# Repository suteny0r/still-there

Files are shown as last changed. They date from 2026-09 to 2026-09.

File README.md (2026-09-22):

# Still There?

*Sentry goin' up.* A face-tracking pan/tilt turret on the Seeed Studio XIAO ESP32S3 Sense.

Camera pan/tilt turret built around the Seeed Studio XIAO ESP32S3 Sense (OV2640, 8 MB PSRAM).
Two MG90S metal-gear servos, on-device person detection (ESPDet-Pico, Espressif's YOLOv11-derived
tiny detector) or face detection (esp-dl) or motion detection, a proportional
tracking loop with scan-when-lost, a laser/LED "fire" output, and a web UI with live MJPEG.
Enclosure is parametric OpenSCAD (2021.01), five printed parts, no supports.

```
firmware/    PlatformIO project (Arduino core 2.0.17, espressif32 6.13.0)
hardware/    turret.scad, render scripts, stl/ output
```

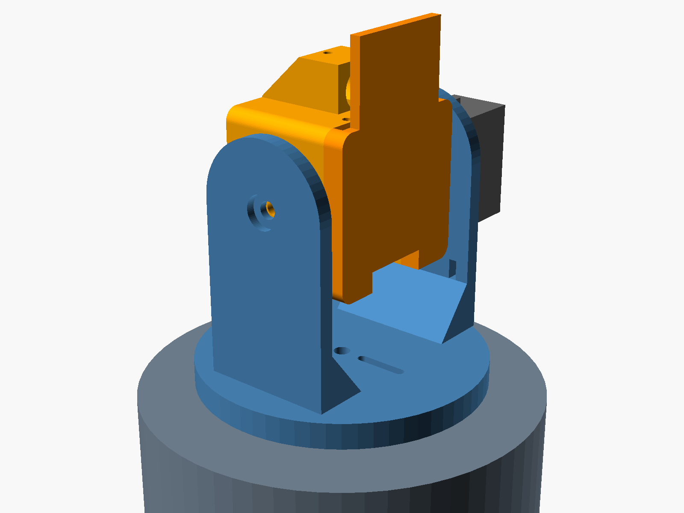
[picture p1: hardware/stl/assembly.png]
assembly


## Bill of materials

Purchase links for everything below except the board and servos: [BOM.md](BOM.md).

| Qty | Item | Notes |
|----:|---|---|
| 1 | Seeed Studio XIAO ESP32S3 Sense | with the camera expansion board fitted |
| 2 | MG90S 9 g metal-gear servo (SupSeek 4-pack or TowerPro) | 2.0 kg-cm @ 6 V, 20T spline, ships with single/double/cross horns |
| 1 | 6 mm laser diode module (optional) | 5 V, fits the saddle on the head |
| 1 | 470 uF+ electrolytic across servo 5 V/GND | servo current spikes reset the board otherwise |
| 1 | 5 V 2 A supply | USB-C into the base inlet or a panel-mount breakout |
| 6 | M2 x 8 self-tapping screws | 4 base lid, 2 head lid |
| 2 | M2 x 8 self-tapping screws | head wall into the single-arm horn (from inside the head) |
| 2 | M2 x 6 self-tapping screws | disc into the double-arm horn (from the top of the disc) |
| 4 | servo ear screws | supplied with the servos: 2 pan servo to base plate, 2 tilt servo to arm A |
| 2 | servo center horn screws | supplied with the servos |
| 1 | M3 x 12 screw | tilt pivot (arm B into the head) |
| 4 | 10 mm rubber feet | recesses in the base lid |

## Wiring

XIAO pin labels on the left, GPIO in brackets. Camera pins (GPIO 10-18, 38-40, 47, 48) and the
LED/SD-CS (GPIO 21) are used by the Sense board; D0-D3 are free.

| XIAO | GPIO | Function |
|---|-----:|---|
| D0 | 1 | pan servo signal |
| D1 | 2 | tilt servo signal |
| D2 | 3 | laser / LED (through a 100 R resistor or a transistor if > 20 mA) |
| D3 | 4 | trigger button to GND (optional, toggles laser) |
| 5V | | servo + laser power (USB 5 V passthrough) |
| GND | | common ground |

Power the servos from the 5 V pin only for bench tests with a supply into USB-C that can source
2 A. For anything more, feed 5 V into the base and run the riser harness up to the head (see
Wiring under Enclosure). The XIAO's own USB-C then stays free for flashing.

## Firmware

Face tracking depends on the esp-dl models that ship with arduino-esp32 **2.0.x**
(`libhuman_face_detect.a`, `libdl.a`). PlatformIO `espressif32 @ 6.13.0` pins that core. The Arduino
IDE with esp32 core 3.x compiles the same sources, but `HAVE_ESP_DL` resolves to 0 there and the Face
mode is disabled in the UI (motion, scan and manual still work).

### Build and flash (PlatformIO)

```
cd firmware
copy include\secrets.h.example include\secrets.h     # edit SSID / password
pio run -t upload
pio device monitor
```

Without `secrets.h` (or with an empty SSID) the turret starts an access point `turret` / `turret123`
at `http://192.168.4.1/`. On a LAN it is reachable at `http://turret.local/`.

Verified builds: PlatformIO env `xiao_esp32s3_sense` (1.53 MB flash, face detection linked), and
`arduino-cli compile --fqbn esp32:esp32:XIAO_ESP32S3:PSRAM=opi` on core 3.3.7 via
`firmware/make_arduino_sketch.ps1` (motion/manual only).

### Runtime

| Task | Core | Job |
|---|-----:|-----|
| `detect` | 1 | grab 240x240 RGB565, person (face acquire + torso color track) or motion (30x30 cell luma diff), feed tracker, draw overlay, JPEG, publish |
| `control` | 1 | 50 Hz: slew servos toward setpoints (rate + smoothing limits), scan sweep, laser |
| httpd :80 | 0 | `/` UI, `/status` JSON, `/control?var=&val=`, `/aim?x=&y=`, `/capture` |
| httpd :81 | 0 | `/stream` MJPEG of the latest published frame |

Tracking law: per detection, `setpoint += kp * (error / half-frame)` outside a pixel deadband;
the control task then moves at most `maxStep` degrees per tick. Motion detection is suppressed for
`settle` ms after any servo motion so the turret does not chase its own panning. After `lost` ms
without a target the pan sweeps between limits (`scan when lost`). When the aim point has stayed
inside the deadband for `lock ms`, the state is LOCK; with Auto-fire on, the laser follows LOCK.
LOCK has hysteresis: correction keeps running while locked, and the lock only releases when the error
exceeds `deadband x lock release` (default 3x) or the target is lost, so a slowly moving target is
followed with the laser held on.

Person mode: the esp-dl face detector (MSR01 + MNP01) only *acquires* the target. As soon as a face
is found, a CAMShift-style color tracker is seeded from the torso region below it (hue/saturation
ratio histogram against the whole frame) and follows the torso frame to frame at camera rate. The
face detector then re-runs every `face re-detect ms` (default 1 s) to re-anchor the track and refresh
the color model; between re-detections the person can turn, look away or walk sideways and the track
holds, because the torso tracker needs neither a frontal face nor a static background. When the color
match drops below `torso min confidence` for `lost` ms the track is dropped and the next face starts a
new one. "Torso color tracking" can be switched off to fall back to face-only tracking.

Aim point: the tracker centers a point `aim below` face-widths under the face center (default 2.3,
the chest; 0 = the face itself). While the torso tracker carries the target the same point is held at
a fixed proportion of the torso window, so it rides along with the person. Face width in pixels scales with 1/distance exactly like any body
offset does, so this is distance-independent: about 2.3 face-widths lands a laser boresighted
parallel to the camera on the chest at any range. The overlay draws the aim point tethered to the
face. The laser saddle sits ~20 mm above the lens, a fixed parallax that is negligible beyond a metre.

All tuning values are live in the web UI and persist to NVS with "Save settings".

Web UI keys: arrows nudge, Space centers, L toggles the laser, 1-4 select mode; click the image to
aim at that point.

Status LED (GPIO 21): fast blink while connecting, slow blink in AP mode, short blink while a
target is fresh, solid on LOCK.

### Servo pulse range

`SERVO_MIN_US`/`SERVO_MAX_US` are 544/2400 us (Arduino Servo defaults), which gives roughly 180 deg on
MG90S units. The TowerPro sheet quotes 1 to 2 ms for +-90; many clones need the wider range for
full travel. Check that neither servo buzzes at 0 or 180 before widening.

### Direction and trims

Scan when lost sweeps pan at "Scan tilt" in every tracking mode (fixed 2026-09-22: it used to hold
whatever tilt the last chase ended on, so it swept the floor or the ceiling). "Tracking tilt max"
(default 110) caps how far a tracking correction may tilt up, so a chase cannot end on the ceiling
lights; manual control keeps the full 35 to 145 range.

Servo orientation decides sign. If the head moves the wrong way, in manual control or by running
away from a target, toggle "Invert pan" or "Invert tilt" and press Save. The flag mirrors the servo
output about 90 degrees, so manual, scan, click-to-aim and tracking all reverse together. Pan/tilt
trim offsets the mechanical center. Both persist.

## Enclosure

`hardware/turret.scad` is a single parametric file. Select a part with `-D part="..."`.

| Part | Print orientation | Notes |
|---|---|---|
| `base` | top plate on the bed | pan servo goes in from below, body up through the plate cut, flange clamped against the two bosses with M2 screws driven up into the pilots; 6 x 12 mm arc slot for the harness outside the disc (a servo plug passes end-on), flat facet on the outside of the +X (back) wall for the USB-C inlet board (mounted outside, face flush, two M2 pilots 16 mm apart drilled from the facet), 13 mm connector slot open to the bottom rim (the lid closes it), vent slots |
| `base_lid` | flat | 4x M2 into wall bosses, rubber-foot recesses, vent grid |
| `yoke` | disc on the bed | double-arm horn channel underneath with two M2 slots and a 3.2 mm center hole; arm A carries the tilt servo (body outside, flange on the outer face) and a zip-tie slot near each edge for the harness; arm B has the M3 pivot with a countersink; arm B sits 2 mm further out than the head frame implies because the tilt horn seats 2 mm high on the spline (`sv_seat_extra_s`) |
| `head` | front face on the bed | camera module socket behind a 7.4 mm window, two standoffs bearing on the flex socket at the camera board's far end, which sits over its board-to-board connector (the end nearest the USB-C hangs free and gets no stop; the XIAO's exposed USB-end corners are the reset/boot buttons), a pad to the USB-C shell, lid posts behind the XIAO; 3 mm deep coax groove in the pivot-side wall; single-arm horn channel on +Y, M3 pivot boss on -Y; USB-C slot in the floor doubles as the harness entry; laser saddle on top (7.3 mm bore for the Quarton module, `laser_d`) with a lead-drop slot behind it; vent slots |
| `head_lid` | antenna plate on the bed | 3 mm friction lip, 2x M2 from the top wall, USB notch, outer face doubled to 4 mm over the whole lid and extended 15 mm above the head as a 2 mm fin for the 20 x 40 WiFi patch antenna (one flat face, prints on the bed), coax notch at the top corner on the pivot side continuing the head's wall groove out through the top edge |

Render everything:

```
cd hardware
powershell -ExecutionPolicy Bypass -File render.ps1      # or: bash render.sh
```

Output goes to `hardware/stl/` (five STLs plus `assembly.png`, `plate.png`). Then run
`python make_project.py --slice` to rebuild the Flash Studio project from the new STLs.
`-D part="assembly"` shows the whole turret with mock servos and board; `-D part="plate"` lays the
five parts out flat.

### Flash Studio project (Creator 5 Pro)

`hardware/turret_creator5pro.3mf` is a ready Flash Studio (Orca-Flashforge 2.4.2) project: all five
parts placed flat on the 256 x 256 plate, printer preset `Flashforge Creator 5 Pro 0.4 nozzle`,
unmodified stock process `0.20mm Standard @FF C5` (0.2 mm, 3 walls, 15 % grid infill, auto brim,
no support), filament `Flashforge PETG Basic @FF C5P`, bed type High Temp Plate (85 C). Open it with File > Open Project, or drag it onto the plate. Swap the filament preset to a
PLA one if you print PLA; the layout and process carry over. `turret_creator5pro_plate.png` shows the
first-layer footprint of each part on the bed. Sliced with these presets: about 3 h 10 min, 73 g of
PETG, no supports, no slicer warnings. Regenerate after CAD changes with `python make_project.py --slice`.
For a partial reprint add `--parts=head,head_lid` (any of base, base_lid, yoke, head, head_lid); the
project is written as `turret_creator5pro_<parts>.3mf`. In Flash Studio you can instead right-click the
unwanted objects and untick **Printable**, or select them and press Delete.

It was produced with the slicer's CLI (`flash studio.exe --load-settings ... --export-3mf`) after
flattening the preset inheritance chains; the CLI refuses system profiles that still carry
`inherits` and no `type` field.

Material: PETG is the better choice for this design. The 3 mm yoke arms, the 2.3 mm wall behind
the horn pocket and the M2 self-tapping pilots all load thin plastic; PETG's layer adhesion and
lower brittleness beat PLA there, and it does not creep under the constant preload of the friction
lip and screws inside a warm enclosure. PLA prints with tighter tolerances and better bridges, so
if you print PLA expect the friction lip to be snugger and drop `lip_clr` to 0.2 only if it turns
out loose. Either way the stock 0.20 mm Flashforge profile is the right starting point: its 3
perimeters fill every thin section of these parts solid, so infill settings barely matter, and no
supports are needed. Clearances (`clr`, `lip_clr`, `m2_*`/`m3_*` pilots) are at the top of `turret.scad`.

### Wiring

Everything electronic except the servos lives in the head, so one harness climbs from the base.
Pins below are the `xiao_espdet` build (the one in the turret): pan D0, tilt D1, laser D2, button D3.
The `*_expansion` builds move tilt to D2 and the laser to D6; do not wire the head from those.
22 AWG silicone wire. The two splice points are small perfboard scraps (about 4 x 6 holes) each
carrying a 3-pin male header so the servo plugs stay intact: the header sits in one row, every wire
gets its own hole in the header pin's row, and the row is bridged with solder. Never two wires on
one header tail.
MG90S lead colors: brown GND, red 5 V, orange signal. Power from one source at a time: either the
base inlet or the XIAO's USB-C, not both.

| Wire | From | To | Cut length |
|---|---|----|---|
| 5 V | inlet V pad | header A (base) -> header B (arm A) -> XIAO 5V pad | 60 + 180 + 80 |
| GND | inlet GND pad | header A -> header B -> XIAO GND pad | 60 + 180 + 80 |
| pan signal | header A (base) | XIAO D0 pad | 260 |
| tilt signal | header B (arm A) | XIAO D1 pad | 80 |
| laser + | XIAO 5V pad | laser red | 40 |
| laser - | laser black | 2N2222 collector; emitter to XIAO GND; base via 1 k to D2 | 40 |

1. **Base.** Screw the inlet board to the flat facet on the OUTSIDE of the back (+X) wall with two M2x4
   self-tapping screws, connector body through the 13 mm slot, solder pads facing the wall (they are
   reached through the slot from inside). The board face must sit at the wall surface or a plug
   cannot reach the receptacle; an inside mount was tried and failed for that reason. Board A: header in one row; row 1 takes the inlet V
   wire and the riser 5 V wire, row 2 the inlet GND wire and the riser GND wire, row 3 the riser
   pan-signal wire; bridge each row. Foam-tape board A to the inside of the lid or tie it to a lid
   boss. Plug the pan servo onto its header: orange on the signal pin. Twist the
   three riser wires, pass them up through the arc slot in the top plate, and leave a 40 mm loop
   above the plate for the pan swing. Screw the lid on.
2. **Yoke.** Zip-tie the riser against arm A's edge through the slot 10 mm above the disc. Board B
   rides under the same tie: row 1 takes the riser 5 V in and the head 5 V out, row 2 the same for
   GND, row 3 the tilt-signal wire from the head; bridge each row. Plug the tilt servo onto its
   header. The pan-signal wire passes board B untouched. (Alternative with no board on the yoke: cut
   the tilt servo plug off and heat-shrink splice its three leads to the riser wires, one joint each.)
3. **Head.** Four wires arrive from header B: 5 V, GND, pan signal, tilt signal. Give them a 20 mm
   loop under the head for the tilt swing and bring them in through the USB-C slot in the floor.
   Solder into the XIAO's plated THROUGH-HOLES from the back face: tinned wire in from the back,
   joint on the back, wire end trimmed flush at the front. Keep solder out of the edge castellations:
   the cavity leaves 0.5 mm per side and any bead on the edge jams the board. Holding the board
   back-face up with the USB-C at the top, the first holes down the RIGHT edge are D0 (pan), D1
   (tilt), D2 (laser), D3 (button), and the first two down the LEFT edge are 5V and GND; the
   silkscreen on the back confirms each one. Keep the joints low: the lid posts land at Y +-3.5
   beside the battery pads. Horn screws: use the two arm holes below the board's USB edge (more than
   11 mm from the hub); a screw head higher up sits against the board edge.
4. **Laser.** Push the module into the saddle, drop its leads through the slot behind the saddle.
   Red to the 5V pad. Black to the 2N2222 collector; emitter to the GND pad; base through 1 k to the
   D2 pad. Heat-shrink the transistor and tuck it behind the XIAO. Optional trigger button: D3 to GND.
5. **Check** before closing: 5 V supply on, both servos center on boot, laser toggles from the web UI,
   no wire crosses the tilt axis without slack. Flashing later: unplug the base inlet, use a
   right-angle USB-C cable in the floor slot beside the harness.

Build status (2026-09-21): prototype assembled and wired as above, person tracking follows a
moving target, laser fires from D2 through the 2N2222 driver. Tilt servo fitted with 2 mm of washers
pending the yoke reprint that moves arm B by the same amount.

### Assembly

1. Center both servos electrically first (flash the firmware, power up, wait for both to hit 90).
2. Base: fit the pan servo from below, body up through the plate cut, flange against the bottom of
   the two bosses, two M2 screws up into the pilots (the disc then rides about 1 mm off the plate).
   Screw the power inlet board to the outside facet (two M2x4), wire the base per Wiring, then screw on the lid.
3. Yoke: seat the **double-arm** horn in the channel under the disc (arms along the camera axis) and
   drive two M2 screws down through the slots into arm holes. Push the yoke onto the pan spline
   with the arms square to the camera direction and drive the horn screw down through the disc
   center hole; its head sits on the disc top. Do NOT fit the tilt servo yet: the head has no axial
   room to engage the spline once the servo is in the arm.
4. Head: lay the **single-arm** horn in the channel on the +Y face, arm pointing down (it may stick
   out ~3.5 mm past the bottom edge; trim it if you like) and drive two M2 screws from inside the head.
   Fit the board stack USB-C down: seat the camera module in the square socket first (lens through the
   window), let the flex socket at the camera board's far end settle onto the two standoffs and the
   USB-C shell onto its pad (nothing presses on the camera board's free end near the USB-C, nor on the
   XIAO's USB-end corners, those are the reset and boot buttons), then press the lid on (its posts stop 0.2 mm off the XIAO
   back) and drive the two M2 screws through the top wall.
5. Antenna (required: the XIAO ESP32S3 has no on-board antenna). The patch's adhesive is on the
   side opposite its coax, so the cable ends up on the exposed face. Stick the 20 x 40 patch to the
   outer face of the lid and fin, centered, top edge about 1 mm below the fin top. Inside the head
   the coax leaves the U.FL over the far edge or sideways at the corner into the 3 mm deep groove in
   the pivot-side wall, runs back along it, and goes straight up through the notch in the lid's top
   corner, out between the head's top wall and the fin. Outside it goes round the fin's side edge
   to the patch center (press one side of the U.FL plug in first, per Seeed). About 40 mm of the
   75 mm cable is used; loop the spare on the fin's inner face behind the laser saddle. `coax_side`
   in `turret.scad` mirrors groove and notch if your U.FL is on the other side.
6. Head onto the yoke: set the head between the arms with the pivot ring against arm B and drive the
   M3x8 through arm B into the ring. Then fit the tilt servo from OUTSIDE arm A, output end first,
   body through the cutout, spline into the horn hub, and drive its two flange screws into the arm.
7. Optional laser: push the module into the saddle bore (7.3 mm for the Quarton), M2 set screw from the top.

### Dimensions that matter

All at the top of `turret.scad`, mm:

- `sv_*`: MG90S envelope from the TowerPro configuration table (A 32.5 ear span, B 22.8 body,
  C 28.4 bottom to spline top, D 12.4 width, F 18.5 bottom to ear top). The body through-cuts use a
  looser 23.6 x 12.8 envelope because clones measure up to 23.9 x 12.7; the ear screws (slotted
  pilots, 27.3 to 28.3 mm spacing) locate the servo.
- Servo and horn dimensions measured on the SupSeek MG90S kit (two units), 2026-09-11:

  | | measured | in CAD |
  |---|---|---|
  | body length x width | 22.8 x 12.4 | 23.6 x 12.8 cut + clearance |
  | ear span (H) | 32.2 | ears rest on the surface, no cut |
  | ear hole spacing | 27.8 / 28.0 | slotted pilots 27.3 to 28.5 |
  | ear top to boss top (K) | 7.3 / 7.5 | 7.4 |
  | hub diameter | 6.8 | 7.4 counterbore |
  | arm plate thickness (E) | 2.0 | 2.6 recess |
  | arm width (D) | 5.1 | 6.1 channel |
  | single arm, center to tip (C) | 18.0 | head channel, open to the bottom edge |
  | double arm, tip to tip (J) | 31.2 | disc channel |
  | single arm: boss top to arm face / hub top | 3.8 / 6.4 | head gap; 5.8 deep hub counterbore (horn wall 6.5) |
  | double arm: boss top to arm face / hub top | 5.85 / 6.26 | disc height; 3.6 deep counterbore (disc 5.0) |

  The kit's cross horn is asymmetric (~31 mm long axis) and does not fit the head, so the pan disc
  takes the **double arm** and the head the **single arm**, pointing down (it extends ~3.5 mm past
  the head's bottom edge; trim it flush if you like). Pockets are rounded channels with one
  continuous M2 screw slot per arm, so hole positions in the horn do not matter. The horn screw on
  the disc sits on top without a countersink. `gap_margin` (0.8) still biases toward the hub seating
  slightly short rather than the head rubbing the arm.
- Board stack (XIAO ESP32S3 **Plus** 17.76 x 21.25 with the camera board, measured 2026-09-13):
  lens front to XIAO back 13.44, lens front to XIAO top face 12.30, 3.0 mm board-to-board gap,
  camera board 18 x 15 (wider than the XIAO, flush with its far end), 8 x 8 module housing with a
  7 mm barrel, lens center 10.8 above the USB edge and on the board centerline. The camera module
  hangs on a short flex and is **not** fixed to the camera board: the head holds it in an 8.6 mm
  square socket behind a 7.4 mm window, so the flex pushes it into the socket. The XIAO is located
  by two pads on its exposed USB-end corners and four lid posts (0.2 mm clearance, no squeeze); two
  standoffs on the flex socket at the camera board's far end and a pad on the USB-C shell are the front stops (0.2 mm clearance)
  without loading the connector. `lens_protrude` (2.3, barrel past the housing face) is derived, not
  measured; the flex absorbs a couple of mm either way.
- `axis_h` 34: tilt axis above the disc. Raise it if you use a straight USB-C plug in the head.
- Tilt limits in firmware (`TILT_MIN_DEG`/`TILT_MAX_DEG`, 35..145) keep the head off the yoke;
  pan is 0..180.

## Known limits

- esp-dl face detection at 240x240 takes 100-200 ms; in Person mode it only runs on acquisition and
  every `face re-detect ms`, so the torso tracker and the stream run at 10-20 fps in between. The
  stream and detection share one frame pipeline, so the stream stutters on re-detect frames.
- The torso tracker is a color tracker: a person whose shirt matches the background, or two people in
  the same shirt, will confuse it. The ratio histogram suppresses background colors but not another
  identical shirt. The face re-detect re-anchors it every second, which limits how far it can wander.
- Motion mode re-references every frame; a target that stops moving disappears until `lost` expires.
- The USB-C slot in the head floor assumes a right-angle cable that runs backward; a straight plug
  hits the yoke disc when tilting down.

## Whole-body person detection: env `xiao_espdet` (default build)

Two firmware flavours live side by side. `xiao_esp32s3_sense` / `xiao_expansion` are the original
esp-dl 1.x face acquisition + torso color tracking on arduino-esp32 2.0.17. `xiao_espdet` (developed
on the `espdet-pico` branch, now merged) swaps the acquisition detector for Espressif's ESPDet-Pico pedestrian model
(esp-dl 3.3.11, `espressif/pedestrian_detect` 0.3.2, 224x224 input). A body box does not need a
frontal face, so masked, turned-away or side-on people are acquired, and the aim point is a fraction
down the box (`aim down body`, default 0.25) instead of "below the face".

ESPDet is Espressif's family of tiny object-detection models (the main variant is ESPDet-Pico)
built for running on ESP32-class microcontrollers. It comes out of the esp-detection project, which
provides a series of ultra-lightweight models along with APIs for training custom detection models
tailored to specific use cases, optimized for efficient deployment on ESP AI chips, and is based on
Ultralytics YOLOv11.

Measured on the XIAO ESP32S3 Sense (2026-09-11): detector 190 to 210 ms per run including the
resize, scores 0.5 to 0.86 on a seated person with a mask, torso tracker 6 to 15 ms between runs,
overall 6 to 7 fps with re-detection every 300 ms, 110 KB heap / 6.7 MB PSRAM free, no resets.

How it is built (no ESP-IDF CMake, no component manager):

- Platform: pioarduino `stable` (Arduino 3.3.6 on the IDF 5.5 SDK), plain `framework = arduino`.
  This is the same platform your other pioarduino projects use. esp-dl 1.x face models do not exist
  on this core, so `HAVE_ESP_DL` is 0 and `HAVE_ESPDET` is 1.
- `firmware/lib/espdl`: esp-dl 3.3.11 subset for ESP32-S3 (dl core, xtensa + TIE-728 assembly
  kernels, fbs_loader, vision/detect, vision/image without JPEG/PPA/YUV/HSV) as a PlatformIO
  library; the prebuilt `libfbs_model.a` is linked by `link_fbs.py`. Kconfig options are supplied
  as `-D` flags in `platformio.ini`.
- `firmware/lib/pedestrian_detect`: the component's `.cpp/.hpp` plus the model, packed with esp-dl's
  `pack_espdl_models.py` and embedded 16-byte aligned through `model/pedestrian_detect_model.S`
  (`.incbin`), which provides the `_binary_pedestrian_detect_espdl_start` symbol the component expects.
- `person_detect.cpp` wraps `PedestrianDetect`; the torso color tracker, lock logic, web UI and
  servo control are unchanged. Person mode seeds the torso tracker from the upper 35 % of the body box.
- Camera task stack is left at the SDK default here; the frame-copy and log-sink fixes from `main`
  still apply.

Build / flash from **PowerShell or VS Code**, not Git Bash: pioarduino's tool installer refuses to
run under MSYS (`ERROR: MSys/Mingw is not supported`) and the compiler is then not found.

    pio run -e xiao_espdet -t upload --upload-port COM13

`xiao_espdet` is the enclosure build: bare XIAO in the head, pins pan D0, tilt D1, laser D2, button
D3 as in the pin table, no OLED or buzzer code. For bench work with the XIAO on the Seeed Expansion
Board use `xiao_espdet_expansion` (same detector; tilt D2, laser D6, button D1, buzzer D3, OLED on
D4/D5). The board in the turret was flashed with `xiao_espdet` on 2026-09-18.

Flash use is 3.0 MB of the 3.3 MB app slot. If it grows, switch `board_build.partitions` to
`max_app_8MB.csv` (drops OTA).

Falling back to the face build is a reflash: `pio run -e xiao_expansion -t upload --upload-port COM6`.
NVS settings are shared (same keys). The turret powers up in the mode that was active when settings
were last saved (default Person).

## Bring-up notes (2026-09-10, board on the XIAO Expansion Board, no servos)

- Build/flash: `pio run -e xiao_expansion -t upload --upload-port COM6`. The expansion env moves the
  tilt servo to D2 and the laser to D6 because the expansion board owns D1 (user button) and D3
  (buzzer); it adds the SSD1306 status page (OLED found at 0x3C) and buzzer cues.
- Camera image was upside down in this mounting: set H-mirror and V-flip in the UI and Save. The
  head-mounted orientation will differ; set it once there.
- Crash found and fixed: panic "Stack canary watchpoint triggered (cam_task)". The camera driver's
  2 KB task logs `EV-VSYNC-OVF` through vprintf whenever a frame is held too long; the newlib lock
  setup inside that printf overflows the stack. Fixes: the detector now copies each frame to PSRAM
  and returns the driver buffer immediately, the driver gets 3 buffers, and the IDF log vprintf is
  replaced with a no-op (`esp_log_level_set` was not sufficient in this SDK build). A bare
  `cam_hal: EV-VSYNC-OVF` line can still show on the console now and then; it comes through the ROM
  printf and is harmless.
- Second crash found and fixed: heap corruption (`StoreProhibited`/`LoadProhibited` in the WiFi task
  a few seconds after the first face detection). `fb_gfx` has no bounds checking at all. Two overlay
  writes left the frame: the face-center marker at `y-2` with the face at the top edge (where
  `aim below` puts it), and the "face NNNms" text placed 14 px above the bottom while the fb_gfx
  font (FreeMonoBold 12pt) draws 24 rows downward. Every overlay primitive, text included, now goes
  through clipped helpers, and the PSRAM work frame has 8 KB guard bands on both sides.
- After the person leaves, the torso color tracker can keep matching background at its minimum
  window size; a track with no detector confirmation for `faceTimeoutMs` is dropped (default 1.5 s
  since 2026-09-22, was 8 s: long enough for a color track on a blank wall to drive a servo to its stop).
- Acquisition gate (2026-09-22): a new track needs two detections within 0.9 s; a single hit on a
  lamp does not repeat, a person does. A box wholly in the top quarter of the frame while tilt is at
  its tracking ceiling is ignored. A torso window that stays put for a second while the servos are
  still slewing is tracking nothing and is dropped.
- LEDC: ESP32-S3 allows at most 14-bit PWM resolution; the servo driver asked for 16 and silently
  failed. Now 14-bit (1.2 us per step at 50 Hz).
- The esp-dl face model does not detect masked faces. Acquisition needs an unmasked, roughly
  frontal face; a mask blocks Person mode acquisition entirely (torso tracking still works once
  acquired).
- Pipeline rates on the S3: 10 fps in Manual (deliberately capped), 15-16 fps in Person mode while
  no face is present (stage-1 detector 6-14 ms), stream to a PC over the AP at the same rate.
- Opening the USB serial port from a host tool resets the board (USB-Serial-JTAG DTR/RTS). Test
  over HTTP and open serial only when you want a fresh boot log.

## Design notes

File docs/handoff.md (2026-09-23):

# Handoff — still-there evaluation (2026-09-22)

## Objective
- Evaluate the codebase at `F:\still-there` — a face-tracking pan/tilt turret firmware + hardware project (architecture, code quality, potential issues, build health) and produce a final evaluation report

## Important Details
- PlatformIO project targeting Seeed Studio XIAO ESP32S3 Sense (OV2640 camera, 8 MB PSRAM, qio_opi)
- espressif32 6.13.0 / Arduino core 2.0.17; **default env `xiao_esp32s3_sense`**
- Three build envs: `xiao_esp32s3_sense`, `xiao_expansion` (SSD1306 + buzzer), ESPDet-Pico (pioarduino / Arduino 3.3.x / IDF 5.5)
- `lib_ignore = espdl, pedestrian_detect` in base — vendored esp-dl 3.x libs excluded from default and expansion envs
- Build flags: `-DFACE_TWO_STAGE=1`, `-DCAMERA_MODEL_XIAO_ESP32S3`, `-DBOARD_HAS_PSRAM`
- Architecture: `detectorTask` (core 1, 240x240 RGB565 -> detect -> tracker -> overlay -> JPEG -> FrameStore), `controlTask` (core 1, 50 Hz servo slew/scan/laser), `httpd` (core 0, :80 UI+JSON, :81 MJPEG), `loop()` (status LED, trigger button)
- **IDF log sink no-op**: `idfLogSink()` replaces `esp_log_set_vprintf` to prevent 2 KB cam_task stack overflow from EV-VSYNC-OVF -> vprintf -> newlib lock creation; ROM printf path still emits the short line (harmless)
- Tracker control: proportional correction (kp=18 deg) outside deadband (12 px), hysteresis lock release via `lockRelease` factor (3.0x deadband), `lockMs=600`, `settleMs=350`, `lostMs=2500`, `maxStep=3 deg/tick`
- `aimPoint()`: FACE -> y + 2.3*w below; PERSON -> y - h/2 + 0.25*h; TORSO -> torsoAimY
- Color tracker: 74-bin (12 hue x 6 sat + dark + gray) normalized ratio histogram; 8-iteration mean-shift; 1.4x search window; 0.05 per-bin threshold; `minConfidence=0.12`
- Motion detection: 30x30 grid, 2 px subsample per cell, luma from RGB565, frame-to-frame differencing with threshold + weighted centroid + bounding box
- Face detection: two-stage MSR01->MNP01 or single-stage; Person detection: `PedestrianDetect` (PICO_S8_V1) with `HAVE_ESPDET`
- Servo: LEDC 50 Hz, LEDC_CH_PAN=2, LEDC_CH_TILT=3, 14-bit (S3 max), range 544-2400 us; PAN 0-180 deg, TILT 35-145 deg, center 90/90
- `trackTiltMax=110 deg` caps tracking tilt; `torsoTrack=true` default
- OLED: I2C bus recovery, probe every 2 s for 30 s, re-init every 15 s; U8g2_SSD1306_128X64
- Camera 240x240, XCLK 20 MHz; `CONTROL_HZ=50`
- Web: MJPEG port 81, JSON port 80, mDNS `turret`; AP fallback `turret`/`turret123`
- Hardware: parametric OpenSCAD enclosure, 2x MG90S metal-gear servos, 5 printed parts
- BOM: PETG Pro filament, M2 self-tapping screws, M3 button-head Torx (tilt pivot), 470 uF electrolytic cap, 5 V 3 A USB-C supply
- web.cpp full review (287 lines, complete):
  - Routes: `/` (INDEX_HTML), `/status` (JSON, no-store), `/control?var=&val=` (GET, all settings, constrained), `/aim?x=&y=` (click-to-aim), `/capture` (single JPEG, heap alloc 96 KB), `/stream` (MJPEG multipart, 96 KB heap alloc, poll for new seq up to 2 s, break on send error, free buf)
  - Two httpd instances (core 0), ctrl_port 32768/32769, ctrl stack 6144; stream cfg `max_open_sockets = 3`
  - CORS `Access-Control-Allow-Origin: *` on control/capture/stream
  - `defaults` handler preserves hmirror/vflip, resets rest
  - `faceOk` reported via HAVE_ESP_DL compile-time, `detector` name: espdet-person / esp-dl-face / none
  - X-Framerate header hard-coded 60 (aspirational, not real)
  - No auth on any endpoint; control is unbounded-GET (CSRF-able from any page pointed at device); no rate limiting at IP level (httpd default connection limits only)
  - `capture_handler` and `stream_handler` malloc 96 KB heap each — concurrent stream + capture = 192 KB heap pressure
- color_tracker.cpp full review (126 lines, complete):
  - mean-shift: 8 iterations, `STEP` subsample (2 px), per-bin threshold v<0.05 skip, m00 minimum 1.0, converge when moved < 1.0 px
  - Window adaptation: `area = m00*STEP*STEP`, aspect from seed, clamp to 0.5x-1.8x seed, EMA 0.7/0.3
  - `_conf = area/(sw*sh)` where sw/sh are the 1.4x windows; minConfidence 0.12
  - `t.kind = TARGET_TORSO` — color tracker is the torso/presence fallback, not face
  - Histogram is a ratio hist (roi/all) normalized by max, so illumination-common modes wash out
  - `binOf` computes hue with integer math from 565 bits; dark (mx<40) and gray (s<40) are separate bins

## Work State
### Completed
- Listed top-level directory structure, globbed all firmware source files
- Read `README.md`, `platformio.ini` (all 3 envs), `tracker.h` (Settings, Mode, API)
- Read `detector.h` (complete), `servo_ctl.h` (complete), `person_detect.cpp` (complete), `web.h` (complete), `display.h` (complete), `frame_store.h` (complete), `camera_pins.h` (complete)
- Read `detector.cpp`: `begin()`, `detectFace()`, `detectMotion()` body (grid luma differencing, centroid, bbox)
- Read `config.h`: WiFi, pins, servo config, mechanical limits, camera, CONTROL_HZ (75 lines, complete)
- Read `display.cpp`: I2C bus recovery, OLED probe, init, `displayBegin`, start of `displayUpdate` (lines 1-54 confirmed; buzzer section and rest of draw not seen)
- Read `main.cpp`: includes, fb_gfx fallback stubs, task architecture comments, `idfLogSink` reference (lines 1-37 confirmed; detectorTask/controlTask/loop not seen)
- Read `web.cpp` **COMPLETE** (287 lines): index/status/control/aim/capture/stream handlers, webBegin config
- Read `tracker.cpp`: `writeServos` (invert about 180 + trim), `begin` (laser pin, LEDC, prefs, center), `setMode`, `aimPoint` start (lines 1-44 confirmed; controlTask tick, scan sweep, `update()` not seen)
- Read `color_tracker.h` (full), `color_tracker.cpp` **COMPLETE** (126 lines): binOf, clampBox, buildHist, init, refresh, track
- Read `docs/session-2026-09-10.md`: original creation request and session transcript (partial)
- Read `BOM.md`: parts list with Amazon links (partial, first 5 rows)

### Active
- Key sections still unreviewed due to truncation: `main.cpp` (detectorTask body, controlTask body, loop()), `tracker.cpp` (controlTask tick, scan sweep logic, `update()`), `display.cpp` (buzzer code, rest of `displayUpdate` draw)
- `index_html.h` (10309 B) not yet read
- `hardware/turret.scad` not yet reviewed
- **Final evaluation report not yet produced**

### Blocked
- (none)

## Next Move
1. Read `main.cpp` detectorTask/controlTask/loop (use offset/limit reads)
2. Read `tracker.cpp` controlTask/scan/update (use offset/limit reads)
3. Read `display.cpp` buzzer section + rest of draw
4. Read `index_html.h` (embedded web UI)
5. Optionally review `hardware/turret.scad`
6. Produce final evaluation report: architecture assessment, code quality observations, potential issues/risks, build health, recommendations

## Relevant Files
- `F:\still-there\README.md`: project overview, features
- `F:\still-there\BOM.md`: parts list with purchase links — partially read
- `F:\still-there\firmware\platformio.ini`: build config, 3 envs, pin/camera flags, lib_ignore
- `F:\still-there\firmware\src\main.cpp` (~19918 B): entry point, idfLogSink, task architecture — detectorTask/controlTask/loop not yet seen
- `F:\still-there\firmware\include\config.h` (75 lines): complete
- `F:\still-there\firmware\src\tracker.h`: Settings struct, Mode enum, Tracker API
- `F:\still-there\firmware\src\tracker.cpp`: writeServos, begin, aimPoint, onDetection — controlTask/scan/update not yet seen
- `F:\still-there\firmware\src\detector.h` (60 lines): complete
- `F:\still-there\firmware\src\detector.cpp`: detectFace, detectMotion (grid luma)
- `F:\still-there\firmware\src\servo_ctl.h` (57 lines): LEDC servo control, complete
- `F:\still-there\firmware\src\person_detect.cpp` (52 lines): ESPDet-Pico person detector, complete
- `F:\still-there\firmware\src\color_tracker.h`: full class definition
- `F:\still-there\firmware\src\color_tracker.cpp` (126 lines): **COMPLETE**
- `F:\still-there\firmware\src\web.h`: HTTP server API, complete
- `F:\still-there\firmware\src\web.cpp` (287 lines): **COMPLETE**
- `F:\still-there\firmware\src\display.h/.cpp`: OLED/buzzer — buzzer / rest of draw not seen
- `F:\still-there\firmware\src\frame_store.h` (46 lines): mutex-protected JPEG buffer, complete
- `F:\still-there\firmware\include\camera_pins.h` (20 lines): OV2640 pins, complete
- `F:\still-there\firmware\src\index_html.h` (10309 B): embedded web UI — not yet read
- `F:\still-there\docs\session-2026-09-10.md`: session transcript — partially read
- `F:\still-there\hardware\turret.scad`: parametric OpenSCAD enclosure — not yet reviewed
- `F:\still-there\hardware\stl\`: exported STL parts
- `F:\still-there\firmware\lib\pedestrian_detect\README.md`: person detector lib notes

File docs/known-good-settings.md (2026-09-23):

# Known-Good Settings

Captured live from `http://192.168.4.1/status` on **2026-09-22** after a full reset-to-defaults plus the intentional changes below. Verified working: face detection, lock, and laser hold steady on a stationary target (no more ~1.5 s lock-loss cycle).

## Intentional changes vs. code defaults

| Setting | Live value | Code default | Purpose |
|---|---|---|---|
| deadbandPx | 41 | 12 | Wider no-correction radius, calmer holding |
| invertPan | true | false | Pan servo wiring direction |
| invertTilt | true | false | Tilt servo wiring direction |
| scanSpeed | 9.0 | 25.0 | Slower lost-target sweep |
| scanTilt | 88.0 | 90.0 | Scan altitude |
| trackTiltMax | 84.0 | 110.0 | Tracking never tilts above this |
| aimFrac | 0.65 | 0.25 | Aim lower down the body box |
| personThr | 0.85 | 0.5 | Stricter person-box score threshold |
| faceTimeout | 25000 ms | 1500 ms | Long grace before dropping color torso track |
| autoFire | true | false | Laser follows lock state |
| motionMinCells | 49 | 3 | Higher motion trigger bar |
| hmirror | true | false | Mirror image for web view |

All other settings are at code defaults (kp=18, smooth=0.35, maxStep=3, settle=350, lost=2500, scan=true, lockMs=600, lockRelease=3.0, aimBelow=2.30, torso=true, redetect=300, torsoConf=0.12, autoFire aside, mthr=22, quality=80, panTrim=0, tiltTrim=0, bootMode=1/Person, mode=Person, detector=espdet-person, vflip=false).

## Full live status snapshot (2026-09-22, untracked/scanning state)

```json
{"mode":1,"pan":53.6,"tilt":88.0,"panSet":53.3,"tiltSet":88.0,"found":false,"fresh":false,"tx":0,"ty":0,"tw":0,"th":0,"score":0.00,"locked":false,"scanning":true,"laser":false,"moving":true,"fps":4.0,"infer":194,"rssi":0,"heap":116376,"psram":6814724,"uptime":2145,"resetReason":1,"faceOk":false,"kp":18.0,"smooth":0.35,"maxStep":3.0,"dead":41,"invPan":true,"invTilt":true,"settle":350,"lost":2500,"scan":true,"scanSpeed":9.0,"scanTilt":88.0,"trackTiltMax":84.0,"lockMs":600,"lockRelease":3.0,"aimBelow":2.30,"torso":true,"redetect":300,"torsoConf":0.12,"kind":0,"faceAge":-1,"faceTimeout":25000,"aimFrac":0.65,"personThr":0.85,"detector":"espdet-person","autoFire":true,"mthr":22,"mmin":49,"quality":80,"hmirror":true,"vflip":false,"panTrim":0.0,"tiltTrim":0.0,"bootMode":1}
```

## Reapplying from scratch (via web API)

Device is AP-mode: SSID `turret`, pass `turret123`, IP `192.168.4.1` (defaults; fine in source).
Endpoint: `GET /control?var=<name>&val=<value>&save=1` (param names per `web.cpp:120-172`).

```
/control?var=invpan&val=1&save=1
/control?var=invtilt&val=1&save=1
/control?var=dead&val=41&save=1
/control?var=scanspeed&val=9.0&save=1
/control?var=scantilt&val=88.0&save=1
/control?var=ttmax&val=84.0&save=1
/control?var=aimfrac&val=0.65&save=1
/control?var=personthr&val=0.85&save=1
/control?var=facetmo&val=25000&save=1
/control?var=autofire&val=1&save=1
/control?var=mmin&val=49&save=1
/control?var=hmirror&val=1&save=1
```

Notes:
- Keep `redetect` (300) well below `faceTimeout` (25000). The original lock-loss bug was `redetect=3700` > old `faceTimeout=1500`, which force-dropped the torso track every 1.5 s (`main.cpp:288`, `tracker.cpp:91`).
- `faceTimeout` is exposed in status as `faceTimeout` but set via var name `facetmo` (`web.cpp:149`).
- The Windows Wi-Fi profile for `turret` was set to auto-connect (connection mode was "manual"), so the AP link now survives device reboots without a manual `netsh wlan connect`.

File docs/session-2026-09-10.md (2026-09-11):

# Turret project session transcript

Source: `session-2026-09-10.jsonl`  
Rendered: 2026-09-10 19:31

## User  `15:23:03`

create a tracking turret using seeedstudio esp32-s3 sense with actuating motors and 3d printable enclosure.  openscad is installed.  seeedstudios esp32-s3 build chain tools are installed.  you may derive from an existing project or create a new one.  blender and F:\openscad-2021.01 are available.

**Tool: Bash** — Inspect working dir and OpenSCAD install

```json
{
 "command": "ls -la /f/turret2 2>/dev/null; echo \"---openscad---\"; ls /f/openscad-2021.01 | head -30"
}
```

**Tool: Bash** — Check ESP32 toolchains

```json
{
 "command": "ls ~/.arduino15 ~/AppData/Local/Arduino15 2>/dev/null | head; echo \"---arduino-cli---\"; which arduino-cli; arduino-cli version 2>/dev/null; echo \"---idf---\"; ls ~/esp 2>/dev/null; ls /c/Espressif 2>/dev/null | head; echo \"---pio---\"; which pio platformio 2>/dev/null"
}
```

<details><summary>result</summary>

```
total 40
drwxr-xr-x 1 User 197121 0 Sep 10 15:18 .
drwxr-xr-x 1 User 197121 0 Sep 10 15:18 ..
---openscad---
color-schemes
examples
fonts
libraries
locale
openscad.com
openscad.exe
templates
```

</details>

<details><summary>result</summary>

```
/c/Users/User/AppData/Local/Arduino15:
inventory.yaml
libraries
library_index.json
library_index.json.sig
package_index.json
package_index.json.sig
packages
staging
tmp
---arduino-cli---
which: no arduino-cli in (/c/Users/User/bin:/mingw64/bin:/usr/local/bin:/usr/bin:/bin:/mingw64/bin:/usr/bin:/c/Users/User/bin:/c/Program Files/NVIDIA GPU Computing Toolkit/CUDA/v12.4/bin:/c/Program Files/NVIDIA GPU Computing Toolkit/CUDA/v12.4/libnvvp:/c/Program Files/Eclipse Adoptium/jdk-11.0.27.6-hotspot/bin:/c/Program Files (x86)/Common Files/Intel/Shared Libraries/redist/intel64/compiler:/c/Program Files/ImageMagick-7.1.0-Q16-HDRI:/c/Program Files (x86)/Common Files/Oracle/Java/javapath:/c/Program Files/Intel/Intel(R) Management Engine Components/iCLS:/c/Windows/system32:/c/Windows:/c/Windows/System32/Wbem:/c/Users/User/AppData/Local/Android/Sdk/platform-tools:/c/Users/User/AppData/Local/Android/Sdk/build-tools/28.0.3:/c/Windows/System32/WindowsPowerShell/v1.0:/c/Program Files (x86)/PivotPrograms/CMS/Backup:/c/WINDOWS/System32/OpenSSH:/c/si:/c/usr/bin:/c/Program Files/Amazon/AWSCLI/bin:/c/Program Files/dotnet:/c/Program Files/VideoLAN/VLC:/c/Program Files/Oracle/VirtualBox:/c/ProgramData/chocolatey/bin:/c/Program Files/ffmpeg-8.1-full_build/bin:/c/WINDOWS/system32:/c/WINDOWS:/c/WINDOWS/System32/Wbem:/c/WINDOWS/System32/WindowsPowerShell/v1.0:/c/WINDOWS/System32/OpenSSH:/c/Program Files (x86)/PDFtk/bin:/c/Users/User/AppData/Roaming/nvm:/c/Program Files/nodejs:/c/Program Files/wooting-analo
... [1550 more chars]
```

</details>

**Tool: Bash** — Check Arduino esp32 core and libraries

```json
{
 "command": "ls /c/Users/User/AppData/Local/Arduino15/packages; echo \"---esp32 vers---\"; ls /c/Users/User/AppData/Local/Arduino15/packages/esp32/hardware/esp32 2>/dev/null; echo \"---libs---\"; ls /c/Users/User/Documents/Arduino/libraries 2>/dev/null | head -40"
}
```

<details><summary>result</summary>

```
The user doesn't want to proceed with this tool use. The tool use was rejected (eg. if it was a file edit, the new_string was NOT written to the file). STOP what you are doing and wait for the user to tell you how to proceed.
```

</details>

## User  `15:23:21`

[Request interrupted by user]

## User  `15:51:53`

<command-name>/model</command-name>
            <command-message>model</command-message>
            <command-args></command-args>

## User  `15:52:05`

create a tracking turret using seeedstudio esp32-s3 sense with actuating motors and 3d printable enclosure.  openscad is installed.  seeedstudios esp32-s3 build chain tools are installed.  you may derive from an existing project or create a new one.  blender and F:\openscad-2021.01 are available.

**Tool: Bash** — Check Arduino esp32 core and PlatformIO platforms

```json
{
 "command": "ls /c/Users/User/AppData/Local/Arduino15/packages 2>/dev/null; echo \"---esp32 core versions---\"; ls /c/Users/User/AppData/Local/Arduino15/packages/esp32/hardware/esp32 2>/dev/null; echo \"---pio platforms---\"; ls ~/.platformio/platforms ~/.platformio/packages 2>/dev/null; pio --version 2>/dev/null"
}
```

<details><summary>result</summary>

```
arduino
builtin
esp32
---esp32 core versions---
3.3.7
---pio platforms---
/c/Users/User/.platformio/packages:
contrib-piohome
framework-arduinoadafruitnrf52
framework-arduinoespressif32
framework-arduinoespressif32-libs
framework-arduinoespressif32@src-f353353c50711ceed98d87e205cb3f0a
framework-arduinopico
framework-arduinoststm32
framework-cmsis
framework-cmsis@2.50700.210515
framework-portduino
tool-adafruit-nrfutil
tool-bossac-nordicnrf52
tool-esp_install
tool-esptoolpy
tool-esptoolpy@2.40900.250804
tool-esptoolpy@src-5614e40fd8102356740511cde9180f8b
tool-mkfatfs
tool-mklittlefs
tool-mklittlefs@1.203.210628
tool-mkspiffs
tool-openocd
tool-openocd-esp32
tool-picotool-rp2040-earlephilhower
tool-riscv32-esp-elf-gdb
tool-scons
tool-sreccat
tool-xtensa-esp-elf-gdb
toolchain-gccarmnoneeabi
toolchain-gccarmnoneeabi@1.90301.200702
toolchain-riscv32-esp
toolchain-riscv32-esp@8.4.0+2021r2-patch5
toolchain-rp2040-earlephilhower
toolchain-xtensa-esp-elf
toolchain-xtensa-esp32
toolchain-xtensa-esp32s3
toolchain-xtensa-esp32s3@8.4.0+2021r2-patch5

/c/Users/User/.platformio/platforms:
espressif32
espressif32@6.11.0
espressif32@6.12.0
espressif32@src-0c646ffc69e540d4590e52b93fa7034a
espressif32@src-3ef53024c39236a937d1df634b8a0383
espressif32@src-7c56f42e1d7d66d9627f0246e8e2d34c
espressif32@src-88f34194123b4b05ff6ef6b8e68c7f60
native
native@src-382fe3ba2950cdde91fd2284e0e60324
native@src-75389b719549da1460e3f7eb69257489
nordicnrf52
nordicnrf52@10.11.0
nordicnrf52@10.9.0
raspberrypi
ststm3
... [48 more chars]
```

</details>

**Tool: Bash** — Check espressif32 platform version, XIAO board defs, bundled libraries

```json
{
 "command": "cat ~/.platformio/platforms/espressif32/platform.json | grep -E '\"version\"|\"name\"' | head -4; ls ~/.platformio/platforms/espressif32/boards | grep -i xiao; cat ~/.platformio/packages/framework-arduinoespressif32/package.json | grep version; ls ~/.platformio/packages/framework-arduinoespressif32/libraries | tr '\\n' ' '"
}
```

**Tool: Bash** — Check camera example and XIAO variant

```json
{
 "command": "ls ~/.platformio/packages/framework-arduinoespressif32/libraries/ESP32/examples/Camera 2>/dev/null; ls ~/.platformio/packages/framework-arduinoespressif32/variants | grep -i xiao; ls ~/.platformio/lib ~/.platformio/lib_deps 2>/dev/null | head"
}
```

<details><summary>result</summary>

```
"name": "espressif32",
  "version": "6.13.0",
      "version": "8.4.0+2021r2-patch5"
      "version": "8.4.0+2021r2-patch5"
seeed_xiao_esp32c3.json
seeed_xiao_esp32c6.json
seeed_xiao_esp32s3.json
  "version": "3.20017.241212+sha.dcc1105b",
ArduinoOTA AsyncUDP BLE BluetoothSerial DNSServer EEPROM ESP32 ESPmDNS Ethernet FFat FS HTTPClient HTTPUpdate HTTPUpdateServer I2S Insights LittleFS NetBIOS Preferences README.md RainMaker SD SD_MMC SPI SPIFFS SimpleBLE Ticker USB Update WebServer WiFi WiFiClientSecure WiFiProv Wire
```

</details>

<details><summary>result</summary>

```
CameraWebServer
XIAO_ESP32C3
XIAO_ESP32S3
```

</details>

**Tool: Bash** — Get XIAO ESP32S3 Sense camera pin map

```json
{
 "command": "grep -n -A 25 \"CAMERA_MODEL_XIAO_ESP32S3\" ~/.platformio/packages/framework-arduinoespressif32/libraries/ESP32/examples/Camera/CameraWebServer/camera_pins.h | head -40"
}
```

<details><summary>result</summary>

```
180:#elif defined(CAMERA_MODEL_XIAO_ESP32S3)
181-#define PWDN_GPIO_NUM     -1
182-#define RESET_GPIO_NUM    -1
183-#define XCLK_GPIO_NUM     10
184-#define SIOD_GPIO_NUM     40
185-#define SIOC_GPIO_NUM     39
186-
187-#define Y9_GPIO_NUM       48
188-#define Y8_GPIO_NUM       11
189-#define Y7_GPIO_NUM       12
190-#define Y6_GPIO_NUM       14
191-#define Y5_GPIO_NUM       16
192-#define Y4_GPIO_NUM       18
193-#define Y3_GPIO_NUM       17
194-#define Y2_GPIO_NUM       15
195-#define VSYNC_GPIO_NUM    38
196-#define HREF_GPIO_NUM     47
197-#define PCLK_GPIO_NUM     13
198-
199-#elif defined(CAMERA_MODEL_ESP32_CAM_BOARD)
200-// The 18 pin header on the board has Y5 and Y3 swapped
201-#define USE_BOARD_HEADER 0 
202-#define PWDN_GPIO_NUM    32
203-#define RESET_GPIO_NUM   33
204-#define XCLK_GPIO_NUM     4
205-#define SIOD_GPIO_NUM    18
```

</details>

**Tool: Bash** — Get XIAO ESP32S3 GPIO to Dx mapping

```json
{
 "command": "cat ~/.platformio/packages/framework-arduinoespressif32/variants/XIAO_ESP32S3/pins_arduino.h | grep -E \"define (D[0-9]+|A[0-9]+|SDA|SCL|SS|MOSI|MISO|SCK|LED_BUILTIN|TX|RX)\" "
}
```

<details><summary>result</summary>

```
#define LED_BUILTIN LED_BUILTIN  // allow testing #ifdef LED_BUILTIN
```

</details>

**Tool: Bash** — Check camera SDK headers and board json

```json
{
 "command": "ls ~/.platformio/packages/framework-arduinoespressif32/tools/sdk/esp32s3/include | grep -i -E \"camera|dl|esp-face|esp-dl|face\"; ls ~/.platformio/packages/framework-arduinoespressif32/tools/sdk/esp32s3/include/esp32-camera/driver/include 2>/dev/null; cat ~/.platformio/platforms/espressif32/boards/seeed_xiao_esp32s3.json"
}
```

<details><summary>result</summary>

```
esp-dl
esp32-camera
esp_camera.h
sensor.h
{

  "build": {

    "arduino": {

      "ldscript": "esp32s3_out.ld",

      "partitions": "default_8MB.csv",

      "memory_type": "qio_opi"

    },

    "core": "esp32",

    "extra_flags": [

      "-DARDUINO_XIAO_ESP32S3",

      "-DBOARD_HAS_PSRAM",

      "-DARDUINO_USB_MODE=1",

      "-DARDUINO_USB_CDC_ON_BOOT=1",

      "-DARDUINO_RUNNING_CORE=1",

      "-DARDUINO_EVENT_RUNNING_CORE=1"

    ],

    "f_cpu": "240000000L",

    "f_flash": "80000000L",

    "flash_mode": "qio",

    "hwids": [

      [

        "0x2886",

        "0x0056"

      ],

      [

        "0x2886",

        "0x8056"

      ]

    ],

    "mcu": "esp32s3",

    "variant": "XIAO_ESP32S3"

  },

  "connectivity": [

    "bluetooth",

    "wifi"

  ],

  "debug": {

    "openocd_target": "esp32s3.cfg"

  },

  "frameworks": [

    "arduino",

    "espidf"

  ],

  "name": "Seeed Studio XIAO ESP32S3",

  "upload": {

    "flash_size": "8MB",

    "maximum_ram_size": 327680,

    "maximum_size": 8388608,

    "require_upload_port": true,

    "speed": 460800

  },

  "url": "https://www.seeedstudio.com/XIAO-ESP32S3-p-5627.html",

  "vendor": "Seeed Studio"

}
```

</details>

**Tool: Bash** — Read XIAO ESP32S3 variant pin definitions

```json
{
 "command": "sed -n 1,80p ~/.platformio/packages/framework-arduinoespressif32/variants/XIAO_ESP32S3/pins_arduino.h"
}
```

<details><summary>result</summary>

```
#ifndef Pins_Arduino_h
#define Pins_Arduino_h

#include <stdint.h>

#define USB_VID 0x2886
#define USB_PID 0x0056

static const uint8_t LED_BUILTIN = 21;
#define BUILTIN_LED  LED_BUILTIN // backward compatibility
#define LED_BUILTIN LED_BUILTIN  // allow testing #ifdef LED_BUILTIN

static const uint8_t TX = 43;
static const uint8_t RX = 44;

static const uint8_t SDA = 5;
static const uint8_t SCL = 6;

static const uint8_t SS   = 44;
static const uint8_t MOSI = 9;
static const uint8_t MISO = 8;
static const uint8_t SCK  = 7;

static const uint8_t A0 = 1;
static const uint8_t A1 = 2;
static const uint8_t A2 = 3;
static const uint8_t A3 = 4;
static const uint8_t A4 = 5;
static const uint8_t A5 = 6;
static const uint8_t A8 = 7;
static const uint8_t A9 = 8;
static const uint8_t A10 = 9;

static const uint8_t D0 = 1;
static const uint8_t D1 = 2;
static const uint8_t D2 = 3;
static const uint8_t D3 = 4;
static const uint8_t D4 = 5;
static const uint8_t D5 = 6;
static const uint8_t D6 = 43;
static const uint8_t D7 = 44;
static const uint8_t D8 = 7;
static const uint8_t D9 = 8;
static const uint8_t D10 = 9;

static const uint8_t T1 = 1;
static const uint8_t T2 = 2;
static const uint8_t T3 = 3;
static const uint8_t T4 = 4;
static const uint8_t T5 = 5;
static const uint8_t T6 = 6;
static const uint8_t T7 = 7;
static const uint8_t T8 = 8;
static const uint8_t T9 = 9;

#endif /* Pins_Arduino_h */
```

</details>

**Tool: Bash** — Check esp-dl face detection headers

```json
{
 "command": "find ~/.platformio/packages/framework-arduinoespressif32/tools/sdk/esp32s3/include/esp-dl -iname \"*face*\" | head; ls ~/.platformio/packages/framework-arduinoespressif32/tools/sdk/esp32s3/include/esp-dl/include 2>/dev/null | head -20"
}
```

**Tool: Bash** — Verify OpenSCAD CLI and Blender

```json
{
 "command": "/f/openscad-2021.01/openscad.com --version 2>&1; which blender; ls \"/c/Program Files/Blender Foundation\" 2>/dev/null"
}
```

<details><summary>result</summary>

```
/c/Users/User/.platformio/packages/framework-arduinoespressif32/tools/sdk/esp32s3/include/esp-dl/include/model_zoo/cat_face_detect_mn03.hpp
/c/Users/User/.platformio/packages/framework-arduinoespressif32/tools/sdk/esp32s3/include/esp-dl/include/model_zoo/face_recognition_112_v1_s16.hpp
/c/Users/User/.platformio/packages/framework-arduinoespressif32/tools/sdk/esp32s3/include/esp-dl/include/model_zoo/face_recognition_112_v1_s8.hpp
/c/Users/User/.platformio/packages/framework-arduinoespressif32/tools/sdk/esp32s3/include/esp-dl/include/model_zoo/face_recognition_tool.hpp
/c/Users/User/.platformio/packages/framework-arduinoespressif32/tools/sdk/esp32s3/include/esp-dl/include/model_zoo/face_recognizer.hpp
/c/Users/User/.platformio/packages/framework-arduinoespressif32/tools/sdk/esp32s3/include/esp-dl/include/model_zoo/human_face_detect_mnp01.hpp
/c/Users/User/.platformio/packages/framework-arduinoespressif32/tools/sdk/esp32s3/include/esp-dl/include/model_zoo/human_face_detect_msr01.hpp
detect
dl_define.hpp
image
layer
math
model_zoo
nn
tool
typedef
```

</details>

**Tool: Bash** — See how the camera example calls face detection

```json
{
 "command": "grep -n -B2 -A12 \"HumanFaceDetectMSR01\\|detect(\" ~/.platformio/packages/framework-arduinoespressif32/libraries/ESP32/examples/Camera/CameraWebServer/app_httpd.cpp | head -80"
}
```

<details><summary>result</summary>

```
Exit code 2
OpenSCAD version 2021.01

which: no blender in (/c/Users/User/bin:/mingw64/bin:/usr/local/bin:/usr/bin:/bin:/mingw64/bin:/usr/bin:/c/Users/User/bin:/c/Program Files/NVIDIA GPU Computing Toolkit/CUDA/v12.4/bin:/c/Program Files/NVIDIA GPU Computing Toolkit/CUDA/v12.4/libnvvp:/c/Program Files/Eclipse Adoptium/jdk-11.0.27.6-hotspot/bin:/c/Program Files (x86)/Common Files/Intel/Shared Libraries/redist/intel64/compiler:/c/Program Files/ImageMagick-7.1.0-Q16-HDRI:/c/Program Files (x86)/Common Files/Oracle/Java/javapath:/c/Program Files/Intel/Intel(R) Management Engine Components/iCLS:/c/Windows/system32:/c/Windows:/c/Windows/System32/Wbem:/c/Users/User/AppData/Local/Android/Sdk/platform-tools:/c/Users/User/AppData/Local/Android/Sdk/build-tools/28.0.3:/c/Windows/System32/WindowsPowerShell/v1.0:/c/Program Files (x86)/PivotPrograms/CMS/Backup:/c/WINDOWS/System32/OpenSSH:/c/si:/c/usr/bin:/c/Program Files/Amazon/AWSCLI/bin:/c/Program Files/dotnet:/c/Program Files/VideoLAN/VLC:/c/Program Files/Oracle/VirtualBox:/c/ProgramData/chocolatey/bin:/c/Program Files/ffmpeg-8.1-full_build/bin:/c/WINDOWS/system32:/c/WINDOWS:/c/WINDOWS/System32/Wbem:/c/WINDOWS/System32/WindowsPowerShell/v1.0:/c/WINDOWS/System32/OpenSSH:/c/Program Files (x86)/PDFtk/bin:/c/Users/User/AppData/Roaming/nvm:/c/Program Files/nodejs:/c/Program Files/wooting-analog-sdk:/c/Program Files/BinDiff/bin:/c/Program Files/WinGet/Links:/cmd:/c/Program Files/edl:/c/Program Files/Calibre2:/c/Program Files/Crucial/Crucial Sto
... [1288 more chars]
```

</details>

<details><summary>result</summary>

```
102-
103-// #if TWO_STAGE
104:// static HumanFaceDetectMSR01 s1(0.1F, 0.5F, 10, 0.2F);
105-// static HumanFaceDetectMNP01 s2(0.5F, 0.3F, 5);
106-// #else
107:// static HumanFaceDetectMSR01 s1(0.3F, 0.5F, 10, 0.2F);
108-// #endif
109-
110-#if CONFIG_ESP_FACE_RECOGNITION_ENABLED
111-static int8_t recognition_enabled = 0;
112-static int8_t is_enrolling = 0;
113-
114-#if QUANT_TYPE
115-    // S16 model
116-    FaceRecognition112V1S16 recognizer;
117-#else
118-    // S8 model
119-    FaceRecognition112V1S8 recognizer;
--
430-     ){
431-#if TWO_STAGE
432:        HumanFaceDetectMSR01 s1(0.1F, 0.5F, 10, 0.2F);
433-        HumanFaceDetectMNP01 s2(0.5F, 0.3F, 5);
434-        std::list<dl::detect::result_t> &candidates = s1.infer((uint16_t *)fb->buf, {(int)fb->height, (int)fb->width, 3});
435-        std::list<dl::detect::result_t> &results = s2.infer((uint16_t *)fb->buf, {(int)fb->height, (int)fb->width, 3}, candidates);
436-#else
437:        HumanFaceDetectMSR01 s1(0.3F, 0.5F, 10, 0.2F);
438-        std::list<dl::detect::result_t> &results = s1.infer((uint16_t *)fb->buf, {(int)fb->height, (int)fb->width, 3});
439-#endif
440-        if (results.size() > 0) {
441-            fb_data_t rfb;
442-            rfb.width = fb->width;
443-            rfb.height = fb->height;
444-            rfb.data = fb->buf;
445-            rfb.bytes_per_pixel = 2;
446-            rfb.format = FB_RGB565;
447-#if ARDUHAL_LOG_LEVEL >= ARDUHAL_LOG_LEVEL_INFO
448-            detected = true;
449-#endif
--
480-

... [1390 more chars]
```

</details>

**Tool: Bash** — Locate camera and esp-dl headers, sdkconfig flags, libs

```json
{
 "command": "SDK=~/.platformio/packages/framework-arduinoespressif32/tools/sdk/esp32s3; find $SDK/include -name \"img_converters.h\" -o -name \"fb_gfx.h\" -o -name \"esp_camera.h\" -o -name \"dl_detect_define.hpp\" -o -name \"sensor.h\" | sed \"s|$SDK/include/||\"; echo \"--- sdkconfig ---\"; grep -E \"FACE|ESP_DL|CAMERA_(MODEL|CONVERTER|JPEG|TASK)|PSRAM_MODE|SPIRAM_MODE\" $SDK/qio_opi/include/sdkconfig.h 2>/dev/null | head -20; echo \"--- libs ---\"; ls $SDK/qio_opi/lib 2>/dev/null | grep -i -E \"dl|camera|face\" ; ls $SDK/lib 2>/dev/null | grep -i -E \"dl|camera|face\""
}
```

<details><summary>result</summary>

```
esp-dl/include/detect/dl_detect_define.hpp
esp32-camera/conversions/include/img_converters.h
esp32-camera/driver/include/esp_camera.h
esp32-camera/driver/include/sensor.h
fb_gfx/include/fb_gfx.h
--- sdkconfig ---
#define CONFIG_SPIRAM_MODE_OCT 1
#define CONFIG_CAMERA_TASK_STACK_SIZE 2048
--- libs ---
libesp32-camera.a
```

</details>

**Tool: Bash** — Read esp-dl detection result types and API signatures

```json
{
 "command": "SDK=~/.platformio/packages/framework-arduinoespressif32/tools/sdk/esp32s3; cat $SDK/include/esp-dl/include/detect/dl_detect_define.hpp; echo \"--- msr01 ctor ---\"; grep -n -A6 \"HumanFaceDetectMSR01(\" $SDK/include/esp-dl/include/model_zoo/human_face_detect_msr01.hpp | head -30; grep -n \"infer(\" $SDK/include/esp-dl/include/model_zoo/human_face_detect_msr01.hpp $SDK/include/esp-dl/include/model_zoo/human_face_detect_mnp01.hpp"
}
```

<details><summary>result</summary>

```
#pragma once

#include <vector>

namespace dl
{
    namespace detect
    {
        typedef struct
        {
            int category;              /*<! category index */
            float score;               /*<! score of box */
            std::vector<int> box;      /*<! [left_up_x, left_up_y, right_down_x, right_down_y] */
            std::vector<int> keypoint; /*<! [x1, y1, x2, y2, ...] */
        } result_t;
    }
}--- msr01 ctor ---
21:    HumanFaceDetectMSR01(const float score_threshold, const float nms_threshold, const int top_k, float resize_scale);
22-
23-    /**
24-     * @brief Destroy the Human Face Detect MSR01 object
25-     */
26:    ~HumanFaceDetectMSR01();
27-
28-    /**
29-     * @brief Inference.
30-     * 
31-     * @tparam T supports uint8_t and uint16_t
32-     *         - uint8_t: input image is RGB888
/c/Users/User/.platformio/packages/framework-arduinoespressif32/tools/sdk/esp32s3/include/esp-dl/include/model_zoo/human_face_detect_msr01.hpp:39:    std::list<dl::detect::result_t> &infer(T *input_element, std::vector<int> input_shape);
/c/Users/User/.platformio/packages/framework-arduinoespressif32/tools/sdk/esp32s3/include/esp-dl/include/model_zoo/human_face_detect_mnp01.hpp:40:    std::list<dl::detect::result_t> &infer(T *input_element, std::vector<int> input_shape, std::list<dl::detect::result_t> &candidates);
```

</details>

**Tool: Bash** — Read fb_gfx, img_converters, and framesize enums

```json
{
 "command": "SDK=~/.platformio/packages/framework-arduinoespressif32/tools/sdk/esp32s3; F=$(find $SDK/include -name fb_gfx.h | head -1); grep -n \"^void\\|^int\\|typedef\\|FB_\" $F | head -30; echo \"--- img_converters ---\"; grep -n \"^bool\\|^size_t\" $(find $SDK/include -name img_converters.h | head -1); echo \"--- framesize ---\"; grep -n \"FRAMESIZE_240X240\\|FRAMESIZE_QVGA\\|FRAMESIZE_96X96\" $(find $SDK/include -name sensor.h | head -1)"
}
```

**Tool: Bash** — Read camera_config_t setup from reference example

```json
{
 "command": "sed -n 1,60p ~/.platformio/packages/framework-arduinoespressif32/libraries/ESP32/examples/Camera/CameraWebServer/CameraWebServer.ino | grep -n -A40 \"camera_config_t config\" | head -60"
}
```

<details><summary>result</summary>

```
14:#ifndef _FB_GFX_H_
15:#define _FB_GFX_H_
21:    typedef enum {
22:        FB_RGB888, FB_BGR888, FB_RGB565, FB_BGR565, FB_GRAY
25:    typedef struct {
44:#endif /* _FB_GFX_H_ */
--- img_converters ---
43:bool fmt2jpg_cb(uint8_t *src, size_t src_len, uint16_t width, uint16_t height, pixformat_t format, uint8_t quality, jpg_out_cb cb, void * arg);
55:bool frame2jpg_cb(camera_fb_t * fb, uint8_t quality, jpg_out_cb cb, void * arg);
72:bool fmt2jpg(uint8_t *src, size_t src_len, uint16_t width, uint16_t height, pixformat_t format, uint8_t quality, uint8_t ** out, size_t * out_len);
84:bool frame2jpg(camera_fb_t * fb, uint8_t quality, uint8_t ** out, size_t * out_len);
99:bool fmt2bmp(uint8_t *src, size_t src_len, uint16_t width, uint16_t height, pixformat_t format, uint8_t ** out, size_t * out_len);
110:bool frame2bmp(camera_fb_t * fb, uint8_t ** out, size_t * out_len);
122:bool fmt2rgb888(const uint8_t *src_buf, size_t src_len, pixformat_t format, uint8_t * rgb_buf);
124:bool jpg2rgb565(const uint8_t *src, size_t src_len, uint8_t * out, jpg_scale_t scale);
--- framesize ---
85:    FRAMESIZE_96X96,    // 96x96
89:    FRAMESIZE_240X240,  // 240x240
90:    FRAMESIZE_QVGA,     // 320x240
```

</details>

<details><summary>result</summary>

```
49:  camera_config_t config;
50-  config.ledc_channel = LEDC_CHANNEL_0;
51-  config.ledc_timer = LEDC_TIMER_0;
52-  config.pin_d0 = Y2_GPIO_NUM;
53-  config.pin_d1 = Y3_GPIO_NUM;
54-  config.pin_d2 = Y4_GPIO_NUM;
55-  config.pin_d3 = Y5_GPIO_NUM;
56-  config.pin_d4 = Y6_GPIO_NUM;
57-  config.pin_d5 = Y7_GPIO_NUM;
58-  config.pin_d6 = Y8_GPIO_NUM;
59-  config.pin_d7 = Y9_GPIO_NUM;
60-  config.pin_xclk = XCLK_GPIO_NUM;
```

</details>

**Tool: Bash** — Check esp-dl static lib presence and link flags

```json
{
 "command": "SDK=~/.platformio/packages/framework-arduinoespressif32/tools/sdk/esp32s3; ls -d $SDK/*/ ; ls $SDK/lib | grep -i -E \"^libdl|esp-dl|face|espressif__\" ; echo \"--- ld flags ---\"; grep -o -E '\"-l[a-z0-9_\\-]*dl[a-z0-9_\\-]*\"|\"-lesp32-camera\"|\"-lfb_gfx\"' ~/.platformio/packages/framework-arduinoespressif32/tools/platformio-build.py | sort -u; echo \"--- face cfg ---\"; grep -rn \"FACE_DETECT\\|ESP_DL\" $SDK/qio_opi/include/sdkconfig.h $SDK/include/sdkconfig.h 2>/dev/null | head"
}
```

<details><summary>result</summary>

```
/c/Users/User/.platformio/packages/framework-arduinoespressif32/tools/sdk/esp32s3/bin/
/c/Users/User/.platformio/packages/framework-arduinoespressif32/tools/sdk/esp32s3/dio_opi/
/c/Users/User/.platformio/packages/framework-arduinoespressif32/tools/sdk/esp32s3/dio_qspi/
/c/Users/User/.platformio/packages/framework-arduinoespressif32/tools/sdk/esp32s3/include/
/c/Users/User/.platformio/packages/framework-arduinoespressif32/tools/sdk/esp32s3/ld/
/c/Users/User/.platformio/packages/framework-arduinoespressif32/tools/sdk/esp32s3/lib/
/c/Users/User/.platformio/packages/framework-arduinoespressif32/tools/sdk/esp32s3/opi_opi/
/c/Users/User/.platformio/packages/framework-arduinoespressif32/tools/sdk/esp32s3/opi_qspi/
/c/Users/User/.platformio/packages/framework-arduinoespressif32/tools/sdk/esp32s3/qio_opi/
/c/Users/User/.platformio/packages/framework-arduinoespressif32/tools/sdk/esp32s3/qio_qspi/
libespressif__esp-dsp.a
libespressif__esp_secure_cert_mgr.a
--- ld flags ---
--- face cfg ---
```

</details>

**Tool: Bash** — Check how build script and example gate face detection

```json
{
 "command": "grep -n -B3 -A3 \"esp-dl\\|FACE_DETECT\" ~/.platformio/packages/framework-arduinoespressif32/tools/platformio-build.py | head -40; grep -n \"FACE_DETECT\" ~/.platformio/packages/framework-arduinoespressif32/libraries/ESP32/examples/Camera/CameraWebServer/app_httpd.cpp | head -5"
}
```

<details><summary>result</summary>

```
29:#define CONFIG_ESP_FACE_DETECT_ENABLED 1
38:#define CONFIG_ESP_FACE_DETECT_ENABLED 0
42:#if CONFIG_ESP_FACE_DETECT_ENABLED
99:#if CONFIG_ESP_FACE_DETECT_ENABLED
171:#if CONFIG_ESP_FACE_DETECT_ENABLED
```

</details>

**Tool: Bash** — Find esp-dl library file and link flag

```json
{
 "command": "SDK=~/.platformio/packages/framework-arduinoespressif32/tools/sdk/esp32s3; ls $SDK/lib | grep -i \"dl\"; echo \"--- build.py libs containing dl ---\"; grep -o -E \"\\-l[A-Za-z0-9_\\-]*dl[A-Za-z0-9_\\-]*\" ~/.platformio/packages/framework-arduinoespressif32/tools/platformio-build.py | sort -u; echo \"--- count libs ---\"; ls $SDK/lib | wc -l"
}
```

<details><summary>result</summary>

```
--- build.py libs containing dl ---
--- count libs ---
98
```

</details>

**Tool: Bash** — Check Arduino IDE CLI and esp32 3.3.7 core toolchain

```json
{
 "command": "ls \"/c/Users/User/AppData/Local/Programs/Arduino IDE/resources/app/lib/backend/resources/\" 2>/dev/null | grep -i cli; ls /c/Users/User/AppData/Local/Arduino15/packages/esp32/tools 2>/dev/null; ls /c/Users/User/AppData/Local/Arduino15/packages/esp32/hardware/esp32/3.3.7/tools/sdk 2>/dev/null; ls /c/Users/User/AppData/Local/Arduino15/packages/esp32/tools/esp32-arduino-libs 2>/dev/null"
}
```

**Tool: Bash** — List installed Arduino libraries and prior PlatformIO projects

```json
{
 "command": "ls /c/Users/User/Documents/Arduino/libraries 2>/dev/null | tr '\\n' ' '; echo; ls /c/Users/User/Documents/PlatformIO/Projects 2>/dev/null | head; ls ~/.platformio/lib 2>/dev/null | head"
}
```

<details><summary>result</summary>

```
Exit code 2
arduino-cli.exe
esp-rv32
esp-x32
esp32-libs
esp32c3-libs
esp32c5-libs
esp32c6-libs
esp32h2-libs
esp32p4-libs
esp32p4_es-libs
esp32s2-libs
esp32s3-libs
esptool_py
mklittlefs
mkspiffs
openocd-esp32
riscv32-esp-elf-gdb
xtensa-esp-elf-gdb
```

</details>

<details><summary>result</summary>

```
I2C_BM8563_RTC Seeed_Arduino_Round_display Seeed_GFX U8g2
```

</details>

**Tool: Bash** — List all PIO SDK esp32s3 static libs

```json
{
 "command": "ls ~/.platformio/packages/framework-arduinoespressif32/tools/sdk/esp32s3/lib | tr '\\n' ' '"
}
```

<details><summary>result</summary>

```
libapp_trace.a libapp_update.a libarduino_tinyusb.a libasio.a libbt.a libcbor.a libcmock.a libcoap.a libcoexist.a libconsole.a libcore.a libcxx.a libdriver.a libefuse.a libesp-tls.a libesp32-camera.a libesp_adc_cal.a libesp_common.a libesp_diagnostics.a libesp_eth.a libesp_event.a libesp_gdbstub.a libesp_hid.a libesp_http_client.a libesp_http_server.a libesp_https_ota.a libesp_https_server.a libesp_insights.a libesp_ipc.a libesp_lcd.a libesp_littlefs.a libesp_local_ctrl.a libesp_netif.a libesp_phy.a libesp_pm.a libesp_rainmaker.a libesp_ringbuf.a libesp_rom.a libesp_schedule.a libesp_serial_slave_link.a libesp_timer.a libesp_websocket_client.a libesp_wifi.a libespcoredump.a libespnow.a libespressif__esp-dsp.a libespressif__esp_secure_cert_mgr.a libexpat.a libfatfs.a libfb_gfx.a libfreemodbus.a libgpio_button.a libhal.a libheap.a libjsmn.a libjson.a libjson_generator.a libjson_parser.a liblibsodium.a liblog.a liblwip.a libmbedcrypto.a libmbedtls.a libmbedtls_2.a libmbedx509.a libmdns.a libmesh.a libmqtt.a libnet80211.a libnewlib.a libnghttp.a libnvs_flash.a libopenssl.a libperfmon.a libpp.a libprotobuf-c.a libprotocomm.a libpthread.a libqrcode.a librmaker_common.a librtc_store.a libsdmmc.a libsmartconfig.a libsoc.a libspiffs.a libtcp_transport.a libtcpip_adapter.a libulp.a libunity.a libusb.a libvfs.a libwapi.a libwear_levelling.a libwifi_provisioning.a libwpa_supplicant.a libws2812_led.a libxt_hal.a libxtensa.a
```

</details>

**Tool: Bash** — Check Arduino 3.3.7 esp32s3 libs for esp-dl and camera

```json
{
 "command": "L=/c/Users/User/AppData/Local/Arduino15/packages/esp32/tools/esp32-libs; ls $L; V=$(ls $L | head -1); ls $L/$V; ls $L/$V/esp32s3/lib 2>/dev/null | grep -i -E \"dl|camera|face|dsp\"; ls $L/$V/esp32s3/include 2>/dev/null | grep -i -E \"dl|camera|face\""
}
```

**Tool: Bash** — Check arduino-cli version, cores, XIAO board FQBN

```json
{
 "command": "CLI=\"/c/Users/User/AppData/Local/Programs/Arduino IDE/resources/app/lib/backend/resources/arduino-cli.exe\"; \"$CLI\" version; \"$CLI\" core list 2>/dev/null; \"$CLI\" board listall 2>/dev/null | grep -i xiao"
}
```

<details><summary>result</summary>

```
3.3.7
bin
dio_qspi
flags
include
ld
lib
qio_qspi
sdkconfig
versions.txt
```

</details>

<details><summary>result</summary>

```
arduino-cli  Version: 1.4.1 Commit: e39419312 Date: 2026-01-19T16:12:56Z
ID          Installed Latest Name
arduino:avr 1.8.7     1.8.7  Arduino AVR Boards
esp32:esp32 3.3.7     3.3.7  esp32

XIAO_ESP32C3                                esp32:esp32:XIAO_ESP32C3
XIAO_ESP32C5                                esp32:esp32:XIAO_ESP32C5
XIAO_ESP32C6                                esp32:esp32:XIAO_ESP32C6
XIAO_ESP32S3                                esp32:esp32:XIAO_ESP32S3
XIAO_ESP32S3_PLUS                           esp32:esp32:XIAO_ESP32S3_Plus
```

</details>

**Tool: Bash** — Search whole SDK for esp-dl prebuilt archives

```json
{
 "command": "SDK=~/.platformio/packages/framework-arduinoespressif32/tools/sdk/esp32s3; find $SDK -iname \"*.a\" | grep -i -E \"dl|face|detect\" ; ls $SDK/include/esp-dl; grep -n \"esp-dl\" ~/.platformio/packages/framework-arduinoespressif32/tools/platformio-build.py | head"
}
```

<details><summary>result</summary>

```
/c/Users/User/.platformio/packages/framework-arduinoespressif32/tools/sdk/esp32s3/ld/libcat_face_detect.a
/c/Users/User/.platformio/packages/framework-arduinoespressif32/tools/sdk/esp32s3/ld/libcolor_detect.a
/c/Users/User/.platformio/packages/framework-arduinoespressif32/tools/sdk/esp32s3/ld/libdl.a
/c/Users/User/.platformio/packages/framework-arduinoespressif32/tools/sdk/esp32s3/ld/libhuman_face_detect.a
include
```

</details>

**Tool: Bash** — Check Arduino 3.3.7 esp32s3-libs for esp-dl and camera

```json
{
 "command": "L=/c/Users/User/AppData/Local/Arduino15/packages/esp32/tools/esp32s3-libs/3.3.7; ls $L; ls $L/lib | grep -i -E \"dl|camera|face|dsp|fb_gfx\"; find $L -iname \"*.a\" | grep -i -E \"dl|face|detect\" | head; ls $L/include | grep -i -E \"dl|camera|face|fb_gfx\""
}
```

<details><summary>result</summary>

```
bin
dio_opi
dio_qspi
esp_sr
flags
include
ld
lib
opi_opi
qio_opi
qio_qspi
sdkconfig
versions.txt
libdl_lib.a
libesp_driver_sdspi.a
libespressif__dl_fft.a
libespressif__esp-dsp.a
libespressif__esp32-camera.a
libfb_gfx.a
/c/Users/User/AppData/Local/Arduino15/packages/esp32/tools/esp32s3-libs/3.3.7/lib/libdl_lib.a
/c/Users/User/AppData/Local/Arduino15/packages/esp32/tools/esp32s3-libs/3.3.7/lib/libespressif__dl_fft.a
espressif__dl_fft
espressif__esp32-camera
fb_gfx
```

</details>

**Tool: Bash** — Confirm PIO build script links esp-dl archives

```json
{
 "command": "grep -n -E \"human_face_detect|\\\"-ldl\\\"|libdl|cat_face\" ~/.platformio/packages/framework-arduinoespressif32/tools/platformio-build.py | head; grep -n \"LIBPATH\" -A6 ~/.platformio/packages/framework-arduinoespressif32/tools/platformio-build.py | head -20"
}
```

<details><summary>result</summary>

```
(Bash completed with no output)
```

</details>

**Tool: Bash** — List XIAO_ESP32S3 board options for arduino-cli

```json
{
 "command": "CLI=\"/c/Users/User/AppData/Local/Programs/Arduino IDE/resources/app/lib/backend/resources/arduino-cli.exe\"; \"$CLI\" board details -b esp32:esp32:XIAO_ESP32S3 2>/dev/null | grep -i -E \"^Option|PSRAM|USB|Partition|CDC\" | head -30"
}
```

<details><summary>result</summary>

```
Option:        Upload Speed                                                 UploadSpeed
Option:        USB Mode                                                     USBMode
               [32mHardware CDC and JTAG[0m                 [32m✔[0m                      [32mUSBMode=hwcdc[0m
               USB-OTG (TinyUSB)                                            USBMode=default
Option:        USB CDC On Boot                                              CDCOnBoot
               [32mEnabled[0m                               [32m✔[0m                      [32mCDCOnBoot=default[0m
               Disabled                                                     CDCOnBoot=cdc
Option:        USB Firmware MSC On Boot                                     MSCOnBoot
               Enabled (Requires USB-OTG Mode)                              MSCOnBoot=msc
Option:        USB DFU On Boot                                              DFUOnBoot
               Enabled (Requires USB-OTG Mode)                              DFUOnBoot=dfu
Option:        Upload Mode                                                  UploadMode
               [32mUART0 / Hardware CDC[0m                  [32m✔[0m                      [32mUploadMode=default[0m
               USB-OTG CDC (TinyUSB)                                        UploadMode=cdc
Option:        CPU Frequency                                                CPUFreq
Option:        Flash Mode                                                   FlashMode

... [1345 more chars]
```

</details>

**Tool: Bash** — Locate library link list in PIO build script

```json
{
 "command": "B=~/.platformio/packages/framework-arduinoespressif32/tools/platformio-build.py; grep -n -E \"esp32-camera|fb_gfx|sdk/esp32s3/ld|LIBPATH|LIBS=\" $B | head -20; echo \"--- lines ---\"; wc -l $B"
}
```

<details><summary>result</summary>

```
201:env.Prepend(LIBS=libs)
--- lines ---
254 /c/Users/User/.platformio/packages/framework-arduinoespressif32/tools/platformio-build.py
```

</details>

**Tool: Bash** — Read PIO build script to see how SDK link config is loaded

```json
{
 "command": "B=~/.platformio/packages/framework-arduinoespressif32/tools/platformio-build.py; sed -n 1,60p $B; echo \"...\"; sed -n 150,210p $B"
}
```

<details><summary>result</summary>

```
# Copyright 2014-present PlatformIO <contact@platformio.org>
#
# Licensed under the Apache License, Version 2.0 (the "License");
# you may not use this file except in compliance with the License.
# You may obtain a copy of the License at
#
#    http://www.apache.org/licenses/LICENSE-2.0
#
# Unless required by applicable law or agreed to in writing, software
# distributed under the License is distributed on an "AS IS" BASIS,
# WITHOUT WARRANTIES OR CONDITIONS OF ANY KIND, either express or implied.
# See the License for the specific language governing permissions and
# limitations under the License.

"""
Arduino

Arduino Wiring-based Framework allows writing cross-platform software to
control devices attached to a wide range of Arduino boards to create all
kinds of creative coding, interactive objects, spaces or physical experiences.

http://arduino.cc/en/Reference/HomePage
"""

# Extends: https://github.com/platformio/platform-espressif32/blob/develop/builder/main.py

from os.path import abspath, basename, isdir, isfile, join
from copy import deepcopy
from SCons.Script import DefaultEnvironment, SConscript

env = DefaultEnvironment()
platform = env.PioPlatform()
board_config = env.BoardConfig()
build_mcu = board_config.get("build.mcu", "").lower()
partitions_name = board_config.get(
    "build.partitions", board_config.get("build.arduino.partitions", "")
)

FRAMEWORK_DIR = platform.get_package_dir("framework-arduinoespressif32")
assert isdir(FRAMEWORK_DIR)

#
# Helpers
#

d
... [2010 more chars]
```

</details>

**Tool: Bash** — Check per-memory-type SDK build config for esp-dl link flags

```json
{
 "command": "ls ~/.platformio/packages/framework-arduinoespressif32/tools/sdk/esp32s3/qio_opi; grep -o -E \"\\-l(dl|human_face_detect|cat_face_detect|esp32-camera|fb_gfx)\\b\" ~/.platformio/packages/framework-arduinoespressif32/tools/sdk/esp32s3/qio_opi/*.py ~/.platformio/packages/framework-arduinoespressif32/tools/sdk/esp32s3/*.py 2>/dev/null | sort -u"
}
```

<details><summary>result</summary>

```
include
libbootloader_support.a
libesp_hw_support.a
libesp_system.a
libfreertos.a
libspi_flash.a
sections.ld
```

</details>

**Tool: Bash** — Confirm esp32s3 PIO build script links libdl and face-detect archives

```json
{
 "command": "B=~/.platformio/packages/framework-arduinoespressif32/tools/platformio-build-esp32s3.py; grep -n -E \"human_face|\\\"dl\\\"|cat_face|esp32-camera|fb_gfx|sdk/esp32s3/ld|LIBPATH\" $B | head -20"
}
```

<details><summary>result</summary>

```
281:        join(FRAMEWORK_DIR, "tools", "sdk", "esp32s3", "include", "esp32-camera", "driver", "include"),
282:        join(FRAMEWORK_DIR, "tools", "sdk", "esp32s3", "include", "esp32-camera", "conversions", "include"),
315:        join(FRAMEWORK_DIR, "tools", "sdk", "esp32s3", "include", "fb_gfx", "include"),
320:    LIBPATH=[
327:        "-lesp_ringbuf", "-lefuse", "-lesp_ipc", "-ldriver", "-lesp_pm", "-lmbedtls", "-lapp_update", "-lbootloader_support", "-lspi_flash", "-lnvs_flash", "-lpthread", "-lesp_gdbstub", "-lespcoredump", "-lesp_phy", "-lesp_system", "-lesp_rom", "-lhal", "-lvfs", "-lesp_eth", "-ltcpip_adapter", "-lesp_netif", "-lesp_event", "-lwpa_supplicant", "-lesp_wifi", "-lconsole", "-llwip", "-llog", "-lheap", "-lsoc", "-lesp_hw_support", "-lxtensa", "-lesp_common", "-lesp_timer", "-lfreertos", "-lnewlib", "-lcxx", "-lapp_trace", "-lasio", "-lbt", "-lcbor", "-lunity", "-lcmock", "-lcoap", "-lnghttp", "-lesp-tls", "-lesp_adc_cal", "-lesp_hid", "-ltcp_transport", "-lesp_http_client", "-lesp_http_server", "-lesp_https_ota", "-lesp_https_server", "-lesp_lcd", "-lprotobuf-c", "-lprotocomm", "-lmdns", "-lesp_local_ctrl", "-lsdmmc", "-lesp_serial_slave_link", "-lesp_websocket_client", "-lexpat", "-lwear_levelling", "-lfatfs", "-lfreemodbus", "-ljsmn", "-ljson", "-llibsodium", "-lmqtt", "-lopenssl", "-lperfmon", "-lspiffs", "-lusb", "-lulp", "-lwifi_provisioning", "-lrmaker_common", "-lesp_diagnostics", "-lrtc_store", "-lesp_insights", "-ljson_parser", "-ljson_generat
... [5887 more chars]
```

</details>

**Tool: Bash** — Get fb_gfx signatures and color convention used by the reference example

```json
{
 "command": "SDK=~/.platformio/packages/framework-arduinoespressif32/tools/sdk/esp32s3; sed -n 20,44p $SDK/include/fb_gfx/include/fb_gfx.h; grep -n \"sccb_i2c_port\\|grab_mode\\|fb_location\" $SDK/include/esp32-camera/driver/include/esp_camera.h | head -5; grep -n \"FACE_COLOR\\|rfb.format\\|fb_gfx_\" ~/.platformio/packages/framework-arduinoespressif32/libraries/ESP32/examples/Camera/CameraWebServer/app_httpd.cpp | head -12"
}
```

<details><summary>result</summary>

```
typedef enum {
        FB_RGB888, FB_BGR888, FB_RGB565, FB_BGR565, FB_GRAY
    } fb_format_t;

    typedef struct {
            int width;
            int height;
            int bytes_per_pixel;
            fb_format_t format;
            uint8_t * data;
    } fb_data_t;

    void     fb_gfx_fillRect     (fb_data_t *fb, int32_t x, int32_t y, int32_t w, int32_t h, uint32_t color);
    void     fb_gfx_drawFastHLine(fb_data_t *fb, int32_t x, int32_t y, int32_t w, uint32_t color);
    void     fb_gfx_drawFastVLine(fb_data_t *fb, int32_t x, int32_t y, int32_t h, uint32_t color);
    uint8_t  fb_gfx_putc         (fb_data_t *fb, int32_t x, int32_t y, uint32_t color, unsigned char c);
    uint32_t fb_gfx_print        (fb_data_t *fb, int32_t x, int32_t y, uint32_t color, const char * str);
    uint32_t fb_gfx_printf       (fb_data_t *fb, int32_t x, int32_t y, uint32_t color, const char *format, ...);

#ifdef __cplusplus
}
#endif

#endif /* _FB_GFX_H_ */
42:        .grab_mode      = CAMERA_GRAB_WHEN_EMPTY
91:} camera_grab_mode_t;
99:} camera_fb_location_t;
151:    camera_fb_location_t fb_location; /*!< The location where the frame buffer will be allocated */
152:    camera_grab_mode_t grab_mode;   /*!< When buffers should be filled */
61:#define FACE_COLOR_WHITE 0x00FFFFFF
62:#define FACE_COLOR_BLACK 0x00000000
63:#define FACE_COLOR_RED 0x000000FF
64:#define FACE_COLOR_GREEN 0x0000FF00
65:#define FACE_COLOR_BLUE 0x00FF0000
66:#define FACE_COLOR_YELLOW (FACE_COLOR_RED | FACE_COLOR_GREE
... [328 more chars]
```

</details>

**Tool: Write**

```json
{
 "file_path": "F:\\turret2\\firmware\\platformio.ini",
 "content": "; Seeed Studio XIAO ESP32S3 Sense tracking turret\n; Toolchain: PlatformIO espressif32 6.13.0 (Arduino core 2.0.17).\n; Arduino 2.0.x ships the esp-dl face-detection archives (libhuman_face_detect, libdl);\n; Arduino 3.x does not, so face tracking is only available with this environment.\n; Motion tracking and manual control build on both.\n\n[platformio]\ndefault_envs = xiao_esp32s3_sense\n\n[env:xiao_esp32s3_sense]\nplatform = espressif32 @ 6.13.0\nboard = seeed_xiao_esp32s3\nframework = arduino\nmonitor_speed = 115200\nupload_speed = 921600\nboard_build.arduino.memory_type = qio_opi\nboard_build.partitions = default_8MB.csv\nboard_build.flash_size = 8MB\nbuild_flags =\n    -DBOARD_HAS_PSRAM\n    -DCAMERA_MODEL_XIAO_ESP32S3\n    -DCORE_DEBUG_LEVEL=1\n    -DFACE_TWO_STAGE=1\n    -Wno-unused-variable\n    -Wno-un\n... [14 more chars]"
}
```

<details><summary>result</summary>

```
File created successfully at: F:\turret2\firmware\platformio.ini (file state is current in your context — no need to Read it back)
```

</details>

**Tool: Write**

```json
{
 "file_path": "F:\\turret2\\firmware\\include\\config.h",
 "content": "#pragma once\n\n// ---------------------------------------------------------------------------\n// WiFi: copy include/secrets.h.example to include/secrets.h and edit.\n// With no secrets.h (or empty SSID) the turret starts its own AP.\n// ---------------------------------------------------------------------------\n#if defined(__has_include)\n#if __has_include(\"secrets.h\")\n#include \"secrets.h\"\n#endif\n#endif\n\n#ifndef WIFI_SSID\n#define WIFI_SSID \"\"\n#endif\n#ifndef WIFI_PASS\n#define WIFI_PASS \"\"\n#endif\n\n#define HOSTNAME        \"turret\"     // http://turret.local\n#define AP_SSID         \"turret\"\n#define AP_PASS         \"turret123\"  // min 8 chars\n#define WIFI_CONNECT_MS 15000\n\n// ---------------------------------------------------------------------------\n// Pins (XIAO ESP32S3 silkscreen -> GPIO). D0..D\n... [1139 more chars]"
}
```

<details><summary>result</summary>

```
File created successfully at: F:\turret2\firmware\include\config.h (file state is current in your context — no need to Read it back)
```

</details>

**Tool: Write**

```json
{
 "file_path": "F:\\turret2\\firmware\\include\\secrets.h.example",
 "content": "#pragma once\n// Copy to include/secrets.h (git-ignored) and fill in.\n#define WIFI_SSID \"your-ssid\"\n#define WIFI_PASS \"your-password\"\n"
}
```

<details><summary>result</summary>

```
File created successfully at: F:\turret2\firmware\include\secrets.h.example (file state is current in your context — no need to Read it back)
```

</details>

**Tool: Write**

```json
{
 "file_path": "F:\\turret2\\firmware\\include\\camera_pins.h",
 "content": "#pragma once\n// Seeed Studio XIAO ESP32S3 Sense, OV2640 on the expansion board.\n// Matches CAMERA_MODEL_XIAO_ESP32S3 in the arduino-esp32 CameraWebServer example.\n#define PWDN_GPIO_NUM   -1\n#define RESET_GPIO_NUM  -1\n#define XCLK_GPIO_NUM   10\n#define SIOD_GPIO_NUM   40\n#define SIOC_GPIO_NUM   39\n\n#define Y9_GPIO_NUM     48\n#define Y8_GPIO_NUM     11\n#define Y7_GPIO_NUM     12\n#define Y6_GPIO_NUM     14\n#define Y5_GPIO_NUM     16\n#define Y4_GPIO_NUM     18\n#define Y3_GPIO_NUM     17\n#define Y2_GPIO_NUM     15\n#define VSYNC_GPIO_NUM  38\n#define HREF_GPIO_NUM   47\n#define PCLK_GPIO_NUM   13\n"
}
```

<details><summary>result</summary>

```
File created successfully at: F:\turret2\firmware\include\camera_pins.h (file state is current in your context — no need to Read it back)
```

</details>

**Tool: Write**

```json
{
 "file_path": "F:\\turret2\\firmware\\src\\servo_ctl.h",
 "content": "#pragma once\n#include <Arduino.h>\n#include \"config.h\"\n\n// Hobby servo on an LEDC channel, 50 Hz, 16-bit duty.\n// Works on arduino-esp32 2.x (ledcSetup/ledcAttachPin) and 3.x (ledcAttachChannel).\nclass ServoOut {\n public:\n  void attach(int pin, int channel, float minDeg, float maxDeg) {\n    _pin = pin;\n    _ch = channel;\n    _min = minDeg;\n    _max = maxDeg;\n#if ESP_ARDUINO_VERSION_MAJOR >= 3\n    ledcAttachChannel(_pin, SERVO_FREQ_HZ, 16, _ch);\n#else\n    ledcSetup(_ch, SERVO_FREQ_HZ, 16);\n    ledcAttachPin(_pin, _ch);\n#endif\n  }\n\n  void writeDeg(float deg) {\n    if (deg < _min) deg = _min;\n    if (deg > _max) deg = _max;\n    _deg = deg;\n    uint32_t us = SERVO_MIN_US + (uint32_t)((SERVO_MAX_US - SERVO_MIN_US) * (deg / 180.0f));\n    writeUs(us);\n  }\n\n  void writeUs(uint32_t us) {\n    const u\n... [541 more chars]"
}
```

<details><summary>result</summary>

```
File created successfully at: F:\turret2\firmware\src\servo_ctl.h (file state is current in your context — no need to Read it back)
```

</details>

**Tool: Write**

```json
{
 "file_path": "F:\\turret2\\firmware\\src\\detector.h",
 "content": "#pragma once\n#include <Arduino.h>\n#include \"esp_camera.h\"\n\n// esp-dl face models ship with arduino-esp32 2.0.x (ESP32-S3 only).\n#if defined(__has_include)\n#if __has_include(\"human_face_detect_msr01.hpp\")\n#define HAVE_ESP_DL 1\n#endif\n#endif\n#ifndef HAVE_ESP_DL\n#define HAVE_ESP_DL 0\n#endif\n\nstruct Target {\n  bool found = false;\n  int x = 0, y = 0;   // center, pixels\n  int w = 0, h = 0;   // box size, pixels\n  float score = 0;\n};\n\nclass Detector {\n public:\n  void begin();\n\n  // RGB565 frame -> largest face.\n  Target detectFace(camera_fb_t* fb);\n\n  // RGB565 frame -> centroid of changed 8x8 cells vs previous frame.\n  // suppress=true only refreshes the reference (use while servos are moving).\n  Target detectMotion(camera_fb_t* fb, bool suppress, int threshold, int minCells);\n\n  void resetMoti\n... [244 more chars]"
}
```

<details><summary>result</summary>

```
File created successfully at: F:\turret2\firmware\src\detector.h (file state is current in your context — no need to Read it back)
```

</details>

**Tool: Write**

```json
{
 "file_path": "F:\\turret2\\firmware\\src\\detector.cpp",
 "content": "#include \"detector.h\"\n#include <string.h>\n#include <stdlib.h>\n\n#if HAVE_ESP_DL\n#include \"human_face_detect_msr01.hpp\"\n#include \"human_face_detect_mnp01.hpp\"\n#ifndef FACE_TWO_STAGE\n#define FACE_TWO_STAGE 1\n#endif\n#endif\n\nvoid Detector::begin() {\n#if HAVE_ESP_DL\n  // Same thresholds as the arduino-esp32 CameraWebServer example.\n#if FACE_TWO_STAGE\n  _s1 = new HumanFaceDetectMSR01(0.1F, 0.5F, 10, 0.2F);\n  _s2 = new HumanFaceDetectMNP01(0.5F, 0.3F, 5);\n#else\n  _s1 = new HumanFaceDetectMSR01(0.3F, 0.5F, 10, 0.2F);\n#endif\n#endif\n  _havePrev = false;\n}\n\nTarget Detector::detectFace(camera_fb_t* fb) {\n  Target t;\n#if HAVE_ESP_DL\n  if (!fb || fb->format != PIXFORMAT_RGB565 || !_s1) return t;\n  HumanFaceDetectMSR01* s1 = (HumanFaceDetectMSR01*)_s1;\n  std::vector<int> shape = {(int)fb->height, (int)fb-\n... [2766 more chars]"
}
```

<details><summary>result</summary>

```
File created successfully at: F:\turret2\firmware\src\detector.cpp (file state is current in your context — no need to Read it back)
```

</details>

**Tool: Write**

```json
{
 "file_path": "F:\\turret2\\firmware\\src\\tracker.h",
 "content": "#pragma once\n#include <Arduino.h>\n#include \"config.h\"\n#include \"servo_ctl.h\"\n#include \"detector.h\"\n\nenum Mode : uint8_t { MODE_MANUAL = 0, MODE_FACE = 1, MODE_MOTION = 2, MODE_SCAN = 3 };\n\nstruct Settings {\n  float kp = 18.0f;          // degrees of servo per unit of normalized error (-1..1)\n  float smooth = 0.35f;      // fraction of remaining error applied per control tick\n  float maxStep = 3.0f;      // max degrees per control tick (50 Hz -> 150 deg/s)\n  int deadbandPx = 12;       // no correction inside this radius from frame center\n  bool invertPan = false;\n  bool invertTilt = false;\n  int settleMs = 350;        // ignore motion for this long after the servos move\n  int lostMs = 2500;         // target lost after this long without a detection\n  bool scanWhenLost = true;  // sweep pan \n... [2090 more chars]"
}
```

<details><summary>result</summary>

```
File created successfully at: F:\turret2\firmware\src\tracker.h (file state is current in your context — no need to Read it back)
```

</details>

**Tool: Write**

```json
{
 "file_path": "F:\\turret2\\firmware\\src\\tracker.cpp",
 "content": "#include \"tracker.h\"\n#include <Preferences.h>\n#include <math.h>\n\nstatic Preferences prefs;\n\nvoid Tracker::begin() {\n  pinMode(PIN_LASER, OUTPUT);\n  digitalWrite(PIN_LASER, LOW);\n  _panServo.attach(PIN_SERVO_PAN, LEDC_CH_PAN, PAN_MIN_DEG, PAN_MAX_DEG);\n  _tiltServo.attach(PIN_SERVO_TILT, LEDC_CH_TILT, TILT_MIN_DEG, TILT_MAX_DEG);\n  loadSettings();\n  _pan = _panSet = PAN_CENTER_DEG;\n  _tilt = _tiltSet = TILT_CENTER_DEG;\n  _panServo.writeDeg(_pan + settings.panTrim);\n  _tiltServo.writeDeg(_tilt + settings.tiltTrim);\n  _lastMoveMs = millis();\n}\n\nfloat Tracker::clampPan(float v) const { return v < PAN_MIN_DEG ? PAN_MIN_DEG : (v > PAN_MAX_DEG ? PAN_MAX_DEG : v); }\nfloat Tracker::clampTilt(float v) const { return v < TILT_MIN_DEG ? TILT_MIN_DEG : (v > TILT_MAX_DEG ? TILT_MAX_DEG : v); }\n\nvoid Tra\n... [5936 more chars]"
}
```

<details><summary>result</summary>

```
File created successfully at: F:\turret2\firmware\src\tracker.cpp (file state is current in your context — no need to Read it back)
```

</details>

**Tool: Write**

```json
{
 "file_path": "F:\\turret2\\firmware\\src\\frame_store.h",
 "content": "#pragma once\n#include <Arduino.h>\n#include <freertos/FreeRTOS.h>\n#include <freertos/semphr.h>\n\n// Latest JPEG frame, produced by the detector task, consumed by HTTP handlers.\nclass FrameStore {\n public:\n  void begin() { _mtx = xSemaphoreCreateMutex(); }\n\n  // Takes ownership of jpg (malloc'd by frame2jpg).\n  void publish(uint8_t* jpg, size_t len) {\n    xSemaphoreTake(_mtx, portMAX_DELAY);\n    if (_buf) free(_buf);\n    _buf = jpg;\n    _len = len;\n    _seq++;\n    xSemaphoreGive(_mtx);\n  }\n\n  uint32_t seq() {\n    xSemaphoreTake(_mtx, portMAX_DELAY);\n    uint32_t s = _seq;\n    xSemaphoreGive(_mtx);\n    return s;\n  }\n\n  // Copies the latest frame into dst. Returns bytes copied (0 if none / too big).\n  size_t copyLatest(uint8_t* dst, size_t cap, uint32_t* seqOut) {\n    size_t n = 0;\n    xSemapho\n... [306 more chars]"
}
```

<details><summary>result</summary>

```
File created successfully at: F:\turret2\firmware\src\frame_store.h (file state is current in your context — no need to Read it back)
```

</details>

**Tool: Write**

```json
{
 "file_path": "F:\\turret2\\firmware\\src\\web.h",
 "content": "#pragma once\n#include \"tracker.h\"\n#include \"frame_store.h\"\n\nstruct Stats {\n  volatile float fps = 0;\n  volatile uint32_t inferMs = 0;\n  volatile uint32_t frameMs = 0;\n};\n\nvoid webBegin(Tracker* tracker, FrameStore* frames, Stats* stats);\n"
}
```

<details><summary>result</summary>

```
File created successfully at: F:\turret2\firmware\src\web.h (file state is current in your context — no need to Read it back)
```

</details>

**Tool: Write**

```json
{
 "file_path": "F:\\turret2\\firmware\\src\\web.cpp",
 "content": "#include \"web.h\"\n#include <WiFi.h>\n#include \"esp_http_server.h\"\n#include \"esp_camera.h\"\n#include \"index_html.h\"\n\nstatic Tracker* g_tracker = nullptr;\nstatic FrameStore* g_frames = nullptr;\nstatic Stats* g_stats = nullptr;\nstatic httpd_handle_t s_ctrl = nullptr;\nstatic httpd_handle_t s_stream = nullptr;\n\n#define PART_BOUNDARY \"123456789000000000000987654321\"\nstatic const char* STREAM_CONTENT_TYPE = \"multipart/x-mixed-replace;boundary=\" PART_BOUNDARY;\nstatic const char* STREAM_BOUNDARY = \"\\r\\n--\" PART_BOUNDARY \"\\r\\n\";\nstatic const char* STREAM_PART = \"Content-Type: image/jpeg\\r\\nContent-Length: %u\\r\\n\\r\\n\";\nstatic const size_t FRAME_CAP = 96 * 1024;\n\nstatic esp_err_t index_handler(httpd_req_t* req) {\n  httpd_resp_set_type(req, \"text/html\");\n  return httpd_resp_send(req, INDEX_HTML, HTTPD_RES\n... [9282 more chars]"
}
```

<details><summary>result</summary>

```
File created successfully at: F:\turret2\firmware\src\web.cpp (file state is current in your context — no need to Read it back)
```

</details>

**Tool: Write**

```json
{
 "file_path": "F:\\turret2\\firmware\\src\\index_html.h",
 "content": "#pragma once\n\nstatic const char INDEX_HTML[] = R\"HTML(<!DOCTYPE html>\n<html><head><meta charset=\"utf-8\"><meta name=\"viewport\" content=\"width=device-width,initial-scale=1\">\n<title>Turret</title>\n<style>\n:root{color-scheme:dark}\nbody{margin:0;background:#111;color:#ddd;font:14px system-ui,sans-serif}\n.wrap{display:flex;flex-wrap:wrap;gap:16px;padding:12px;max-width:1100px;margin:auto}\n.view{flex:1 1 360px;min-width:300px}\n.panel{flex:1 1 300px;min-width:280px}\n#img{width:100%;max-width:480px;aspect-ratio:1;background:#000;display:block;border:1px solid #333;cursor:crosshair;image-rendering:auto}\n.row{display:flex;gap:6px;flex-wrap:wrap;align-items:center;margin:6px 0}\nbutton{background:#2a2a2a;color:#eee;border:1px solid #444;border-radius:4px;padding:6px 10px;cursor:pointer}\nbutton.on{backg\n... [7665 more chars]"
}
```

<details><summary>result</summary>

```
File created successfully at: F:\turret2\firmware\src\index_html.h (file state is current in your context — no need to Read it back)
```

</details>

**Tool: Write**

```json
{
 "file_path": "F:\\turret2\\firmware\\src\\main.cpp",
 "content": "// Tracking turret: Seeed Studio XIAO ESP32S3 Sense + 2x SG90/MG90S pan-tilt.\n//\n// Tasks:\n//   detectorTask (core 1): grab RGB565 240x240 frame -> face (esp-dl) or motion\n//                          detection -> feed tracker -> draw overlay -> JPEG -> FrameStore\n//   controlTask  (core 1): 50 Hz servo slew / scan / laser\n//   httpd (core 0):        :80 UI + JSON + control, :81 MJPEG stream\n//   loop():                status LED, trigger button\n\n#include <Arduino.h>\n#include <WiFi.h>\n#include <ESPmDNS.h>\n#include \"esp_camera.h\"\n#include \"img_converters.h\"\n#include \"fb_gfx.h\"\n#include \"config.h\"\n#include \"camera_pins.h\"\n#include \"detector.h\"\n#include \"tracker.h\"\n#include \"frame_store.h\"\n#include \"web.h\"\n\nstatic Detector detector;\nstatic Tracker tracker;\nstatic FrameStore frames;\nstatic Stat\n... [7651 more chars]"
}
```

<details><summary>result</summary>

```
File created successfully at: F:\turret2\firmware\src\main.cpp (file state is current in your context — no need to Read it back)
```

</details>

**Tool: Write**

```json
{
 "file_path": "F:\\turret2\\firmware\\.gitignore",
 "content": ".pio/\n.vscode/\ninclude/secrets.h\n"
}
```

<details><summary>result</summary>

```
File created successfully at: F:\turret2\firmware\.gitignore (file state is current in your context — no need to Read it back)
```

</details>

**Tool: Bash** — Compile firmware with PlatformIO

```json
{
 "command": "cd /f/turret2/firmware && pio run -e xiao_esp32s3_sense 2>&1 | tail -60",
 "timeout": 600000,
 "run_in_background": true
}
```

<details><summary>result</summary>

```
Command running in background with ID: b7849yuqy. Output is being written to: F:\TEMP\claude\F--turret2\a5ef03f6-cf40-4ca1-beaf-7fb67624334e\tasks\b7849yuqy.output. You will be notified when it completes. To check interim output, use Read on that file path.
Session cwd remains F:\turret2; directory changes made by the backgrounded command do not apply to subsequent commands.
```

</details>

**Tool: Write**

```json
{
 "file_path": "F:\\turret2\\hardware\\turret.scad",
 "content": "// =============================================================================\n//  Tracking turret enclosure for Seeed Studio XIAO ESP32S3 Sense + 2x SG90/MG90S\n//  OpenSCAD 2021.01\n//\n//  Parts (select with -D part=\"<name>\"):\n//    base       pan servo housing, open bottom\n//    base_lid   bottom cover for the base (4x M2 screws, rubber-foot recesses)\n//    yoke       pan platform: disc on the pan horn + two arms carrying the tilt axis\n//    head       camera housing for the XIAO + Sense board (open back)\n//    head_lid   back cover for the head (friction lip + 2x M2)\n//    assembly   everything in place with mock servos / board, for preview\n//    plate      all printable parts laid out flat\n//\n//  Coordinate convention (assembly): Z up, camera looks along +X.\n//  Every part module is a\n... [18497 more chars]"
}
```

<details><summary>result</summary>

```
File created successfully at: F:\turret2\hardware\turret.scad (file state is current in your context — no need to Read it back)
```

</details>

**Tool: Bash** — Show firmware build result

```json
{
 "command": "tail -25 \"/f/TEMP/claude/F--turret2/a5ef03f6-cf40-4ca1-beaf-7fb67624334e/tasks/b7849yuqy.output\""
}
```

<details><summary>result</summary>

```
Compiling .pio\build\xiao_esp32s3_sense\FrameworkArduino\esp32-hal-tinyusb.c.o

Compiling .pio\build\xiao_esp32s3_sense\FrameworkArduino\esp32-hal-touch.c.o

Compiling .pio\build\xiao_esp32s3_sense\FrameworkArduino\esp32-hal-uart.c.o

Compiling .pio\build\xiao_esp32s3_sense\FrameworkArduino\firmware_msc_fat.c.o

Compiling .pio\build\xiao_esp32s3_sense\FrameworkArduino\libb64\cdecode.c.o

Compiling .pio\build\xiao_esp32s3_sense\FrameworkArduino\libb64\cencode.c.o

Compiling .pio\build\xiao_esp32s3_sense\FrameworkArduino\main.cpp.o

Compiling .pio\build\xiao_esp32s3_sense\FrameworkArduino\stdlib_noniso.c.o

Compiling .pio\build\xiao_esp32s3_sense\FrameworkArduino\wiring_pulse.c.o

Compiling .pio\build\xiao_esp32s3_sense\FrameworkArduino\wiring_shift.c.o

Archiving .pio\build\xiao_esp32s3_sense\libFrameworkArduino.a

Linking .pio\build\xiao_esp32s3_sense\firmware.elf

Retrieving maximum program size .pio\build\xiao_esp32s3_sense\firmware.elf

Checking size .pio\build\xiao_esp32s3_sense\firmware.elf

Advanced Memory Usage is available via "PlatformIO Home > Project Inspect"

RAM:   [==        ]  20.9% (used 68532 bytes from 327680 bytes)

Flash: [=====     ]  45.9% (used 1533797 bytes from 3342336 bytes)

Building .pio\build\xiao_esp32s3_sense\firmware.bin

esptool.py v4.11.0

Creating esp32s3 image...

Merged 2 ELF sections

Successfully created esp32s3 image.

========================= [SUCCESS] Took 28.98 seconds =========================

[exited with code 0]
```

</details>

**Tool: Bash** — Preview-render the assembly to PNG to check for OpenSCAD errors

```json
{
 "command": "cd /f/turret2/hardware && mkdir -p stl && time /f/openscad-2021.01/openscad.com -o stl/_check.png --imgsize=1400,1000 --camera=140,-170,150,0,0,60 --projection=p --colorscheme=Tomorrow -D 'part=\"assembly\"' turret.scad 2>&1 | grep -v \"^$\" | head -30",
 "timeout": 300000
}
```

<details><summary>result</summary>

```
Compiling design (CSG Products normalization)...
Normalized CSG tree has 128 elements
Geometries in cache: 80
Geometry cache size in bytes: 462872
CGAL Polyhedrons in cache: 0
CGAL cache size in bytes: 0
Total rendering time: 0:00:00.609

real	0m0.900s
user	0m0.000s
sys	0m0.000s
```

</details>

**Tool: Read**

```json
{
 "file_path": "F:\\turret2\\hardware\\stl\\_check.png"
}
```

**Tool: Bash** — Check firmware build log for warnings in project sources

```json
{
 "command": "grep -i -E \"warning|error\" \"/f/TEMP/claude/F--turret2/a5ef03f6-cf40-4ca1-beaf-7fb67624334e/tasks/b7849yuqy.output\" | grep -v \"^Compiling\" | head -20"
}
```

<details><summary>result</summary>

```
(Bash completed with no output)
```

</details>

**Tool: Bash** — Remove duplicate print-orientation modules from the SCAD file

```json
{
 "command": "python - <<'EOF'\nimport re\ns=open('turret.scad',encoding='utf-8').read()\nstart=s.index('module print_base()')\nend=s.index('if (part == \"base\")')\nnew='''module print_base()     { translate([0, 0, base_h]) mirror([0, 0, 1]) base(); }          // top plate on the bed\nmodule print_base_lid() { base_lid(); }\nmodule print_yoke()     { translate([0, 0, -disc_z0]) yoke(); }\nmodule print_head()     { translate([0, 0, -head_x0]) rotate([0, -90, 0]) head(); }          // front face on the bed\nmodule print_head_lid() { translate([0, 0, head_x1 + lid_t]) rotate([0, 90, 0]) head_lid(); } // outer face on the bed\n\n'''\ns=s[:start]+new+s[end:]\ns=s.replace('print_head_fixed()','print_head()').replace('print_head_lid_fixed()','print_head_lid()')\nopen('turret.scad','w',encoding='utf-8').write(s)\nEOF\ngrep -n \"print_head\\|module plate\" turret.scad"
}
```

<details><summary>result</summary>

```
386:module print_head()     { translate([0, 0, -head_x0]) rotate([0, -90, 0]) head(); }          // front face on the bed
387:module print_head_lid() { translate([0, 0, head_x1 + lid_t]) rotate([0, 90, 0]) head_lid(); } // outer face on the bed
392:else if (part == "head")     print_head();
393:else if (part == "head_lid") print_head_lid();
398:  translate([95, 60, 0]) print_head();
399:  translate([95, 100, 0]) print_head_lid();
```

</details>

**Tool: Bash** — Render side, front, plate, and head views for geometry check

```json
{
 "command": "O=/f/openscad-2021.01/openscad.com; \\\n$O -o stl/_side.png  --imgsize=1400,1000 --camera=0,200,110,0,0,80 --projection=o --colorscheme=Tomorrow -D 'part=\"assembly\"' turret.scad 2>&1 | grep -i -E \"warn|error\"; \\\n$O -o stl/_front.png --imgsize=1400,1000 --camera=-200,0,110,0,0,95 --projection=o --colorscheme=Tomorrow -D 'part=\"assembly\"' turret.scad 2>&1 | grep -i -E \"warn|error\"; \\\n$O -o stl/_plate.png --imgsize=1600,1100 --camera=60,50,220,60,50,0 --projection=o --colorscheme=Tomorrow -D 'part=\"plate\"' turret.scad 2>&1 | grep -i -E \"warn|error\"; \\\n$O -o stl/_plate_iso.png --imgsize=1600,1100 --camera=60,-120,160,60,50,0 --projection=p --colorscheme=Tomorrow -D 'part=\"plate\"' turret.scad 2>&1 | grep -i -E \"warn|error\"; \\\n$O -o stl/_head_back.png --imgsize=1200,900 --camera=60,40,40,0,0,10 --projection=p --colorscheme=Tomorrow -D 'part=\"head\"' turret.scad 2>&1 | grep -i -E \"warn|error\"; echo done",
 "timeout": 300000
}
```

**Tool: Bash** — Export all five parts to STL with CGAL

```json
{
 "command": "for p in base base_lid yoke head head_lid; do echo \"== $p\"; /f/openscad-2021.01/openscad.com -o stl/$p.stl -D \"part=\\\"$p\\\"\" turret.scad 2>&1 | grep -i -E \"warn|error|Simple|Total rendering\"; done; ls -la stl/*.stl",
 "timeout": 600000,
 "run_in_background": true
}
```

<details><summary>result</summary>

```
done
```

</details>

<details><summary>result</summary>

```
Command running in background with ID: bmdy72fan. Output is being written to: F:\TEMP\claude\F--turret2\a5ef03f6-cf40-4ca1-beaf-7fb67624334e\tasks\bmdy72fan.output. You will be notified when it completes. To check interim output, use Read on that file path.
```

</details>

**Tool: Write**

```json
{
 "file_path": "F:\\turret2\\hardware\\render.ps1",
 "content": "# Export every printable part to hardware/stl and render preview PNGs.\n# Usage: powershell -ExecutionPolicy Bypass -File render.ps1 [-OpenScad F:\\openscad-2021.01\\openscad.com]\nparam(\n  [string]$OpenScad = \"F:\\openscad-2021.01\\openscad.com\"\n)\n$ErrorActionPreference = \"Stop\"\nSet-Location $PSScriptRoot\nNew-Item -ItemType Directory -Force stl | Out-Null\n\n$parts = @(\"base\", \"base_lid\", \"yoke\", \"head\", \"head_lid\")\nforeach ($p in $parts) {\n  Write-Host \"== $p\"\n  & $OpenScad -o \"stl\\$p.stl\" -D \"part=`\"$p`\"\" turret.scad\n}\n\nWrite-Host \"== previews\"\n& $OpenScad -o \"stl\\assembly.png\" --imgsize=1600,1200 --camera=140,-170,150,0,0,60 --projection=p --colorscheme=Tomorrow -D 'part=\"assembly\"' turret.scad\n& $OpenScad -o \"stl\\plate.png\"    --imgsize=1600,1100 --camera=60,-120,160,60,50,0 --projection=p --\n... [77 more chars]"
}
```

<details><summary>result</summary>

```
File created successfully at: F:\turret2\hardware\render.ps1 (file state is current in your context — no need to Read it back)
```

</details>

**Tool: Write**

```json
{
 "file_path": "F:\\turret2\\hardware\\render.sh",
 "content": "#!/usr/bin/env bash\n# Export every printable part to hardware/stl and render preview PNGs.\n# Usage: ./render.sh [path/to/openscad]\nset -e\ncd \"$(dirname \"$0\")\"\nOPENSCAD=\"${1:-/f/openscad-2021.01/openscad.com}\"\nmkdir -p stl\nfor p in base base_lid yoke head head_lid; do\n  echo \"== $p\"\n  \"$OPENSCAD\" -o \"stl/$p.stl\" -D \"part=\\\"$p\\\"\" turret.scad\ndone\necho \"== previews\"\n\"$OPENSCAD\" -o stl/assembly.png --imgsize=1600,1200 --camera=140,-170,150,0,0,60 --projection=p --colorscheme=Tomorrow -D 'part=\"assembly\"' turret.scad\n\"$OPENSCAD\" -o stl/plate.png    --imgsize=1600,1100 --camera=60,-120,160,60,50,0 --projection=p --colorscheme=Tomorrow -D 'part=\"plate\"' turret.scad\necho \"done -> stl/\"\n"
}
```

<details><summary>result</summary>

```
File created successfully at: F:\turret2\hardware\render.sh (file state is current in your context — no need to Read it back)
```

</details>

**Tool: Write**

```json
{
 "file_path": "F:\\turret2\\firmware\\make_arduino_sketch.ps1",
 "content": "# Assemble an Arduino-IDE sketch folder from the PlatformIO sources.\n# Output: firmware/arduino/turret/turret.ino + all .h/.cpp side by side.\n#\n# Build in the IDE with: Tools > Board > esp32 > XIAO_ESP32S3, PSRAM: \"OPI PSRAM\".\n# Or with arduino-cli:\n#   arduino-cli compile --fqbn esp32:esp32:XIAO_ESP32S3:PSRAM=opi arduino/turret\n#\n# Note: arduino-esp32 3.x has no esp-dl, so face tracking is compiled out there\n# (motion tracking, scan and manual modes still work). Use PlatformIO for face tracking.\n$ErrorActionPreference = \"Stop\"\nSet-Location $PSScriptRoot\n$out = \"arduino\\turret\"\nNew-Item -ItemType Directory -Force $out | Out-Null\nGet-ChildItem \"$out\\*\" -Include *.h,*.cpp,*.ino | Remove-Item -Force\nCopy-Item include\\*.h $out\nif (Test-Path include\\secrets.h) { Copy-Item include\\secrets.h $out\n... [192 more chars]"
}
```

<details><summary>result</summary>

```
File created successfully at: F:\turret2\firmware\make_arduino_sketch.ps1 (file state is current in your context — no need to Read it back)
```

</details>

**Tool: Read**

```json
{
 "file_path": "F:\\turret2\\hardware\\stl\\_side.png"
}
```

**Tool: Read**

```json
{
 "file_path": "F:\\turret2\\hardware\\stl\\_front.png"
}
```

**Tool: Read**

```json
{
 "file_path": "F:\\turret2\\hardware\\stl\\_plate_iso.png"
}
```

**Tool: Read**

```json
{
 "file_path": "F:\\turret2\\hardware\\stl\\_head_back.png"
}
```

**Tool: Bash** — Generate Arduino sketch and compile it with arduino-cli on core 3.3.7

```json
{
 "command": "cd /f/turret2/firmware && powershell -ExecutionPolicy Bypass -File make_arduino_sketch.ps1 && ls arduino/turret && CLI=\"/c/Users/User/AppData/Local/Programs/Arduino IDE/resources/app/lib/backend/resources/arduino-cli.exe\" && \"$CLI\" compile --fqbn esp32:esp32:XIAO_ESP32S3:PSRAM=opi --warnings default arduino/turret 2>&1 | grep -v \"^$\" | tail -25",
 "timeout": 600000,
 "run_in_background": true
}
```

<details><summary>result</summary>

```
Command running in background with ID: bhupi57vn. Output is being written to: F:\TEMP\claude\F--turret2\a5ef03f6-cf40-4ca1-beaf-7fb67624334e\tasks\bhupi57vn.output. You will be notified when it completes. To check interim output, use Read on that file path.
Session cwd remains F:\turret2\hardware; directory changes made by the backgrounded command do not apply to subsequent commands.
```

</details>

**Tool: Bash** — Fix horn pocket through-holes, drop unused variable, render head and yoke undersides

```json
{
 "command": "python - <<'EOF'\ns=open('turret.scad',encoding='utf-8').read()\nold='''module horn_pocket(through = 8) {\n  translate([0, 0, -horn_pocket]) cylinder(d = sv_horn_d + 2*clr, h = horn_pocket + 0.01);\n  translate([0, 0, -through]) cylinder(d = 4.6, h = through + 1);            // center screw\n  for (a = [0, 90, 180, 270]) rotate([0, 0, a])\n    hull() {\n      translate([5.0, 0, -through]) cylinder(d = 1.9, h = through + 1);\n      translate([9.5, 0, -through]) cylinder(d = 1.9, h = through + 1);\n    }\n}'''\nnew='''module horn_pocket(through = 8) {\n  translate([0, 0, -horn_pocket]) cylinder(d = sv_horn_d + 2*clr, h = horn_pocket + 0.01);\n  translate([0, 0, -through]) cylinder(d = 4.6, h = 2*through);              // center screw\n  for (a = [0, 90, 180, 270]) rotate([0, 0, a])\n    hull() {\n      translate([5.0, 0, -through]) cylinder(d = 1.9, h = 2*through);\n      translate([9.5, 0, -through]) cylinder(d = 1.9, h = 2*through);\n    }\n}'''\nassert old in s\ns=s.replace(old,new)\nold2='''  // triangular fillet from the arm inner face down onto the disc\n  s = y_in < y_out ? 1 : -1;                 // +1: arm B (inner face toward +Y)... generic\n  dir = (y_in > 0) ? -1 : 1;                 // direction from arm toward disc center'''\nnew2='''  // triangular fillet from the arm inner face down onto the disc\n  dir = (y_in > 0) ? -1 : 1;                 // direction from arm toward disc center'''\nassert old2 in s\ns=s.replace(old2,new2)\nopen('turret.scad','w',encoding='utf-8').write(s)\nprint(\"ok\")\nEOF\n/f/openscad-2021.01/openscad.com -o stl/_head_bot
... [397 more chars]
```

<details><summary>result</summary>

```
ok

rendered
```

</details>

**Tool: Read**

```json
{
 "file_path": "F:\\turret2\\hardware\\stl\\_head_bottom.png"
}
```

**Tool: Read**

```json
{
 "file_path": "F:\\turret2\\hardware\\stl\\_yoke_bottom.png"
}
```

**Tool: Bash** — Show Arduino 3.3.7 compile result and STL export log

```json
{
 "command": "tail -8 \"/f/TEMP/claude/F--turret2/a5ef03f6-cf40-4ca1-beaf-7fb67624334e/tasks/bhupi57vn.output\"; echo \"=== stl ===\"; cat \"/f/TEMP/claude/F--turret2/a5ef03f6-cf40-4ca1-beaf-7fb67624334e/tasks/bmdy72fan.output\" | grep -E \"^==|Simple|Total|WARN|ERR\""
}
```

<details><summary>result</summary>

```
tracker.h
turret.ino
web.cpp
web.h
Sketch uses 1041361 bytes (31%) of program storage space. Maximum is 3342336 bytes.
Global variables use 67332 bytes (20%) of dynamic memory, leaving 260348 bytes for local variables. Maximum is 327680 bytes.

[exited with code 0]
=== stl ===
== base
Total rendering time: 0:00:07.118
   Simple:        yes
== base_lid
Total rendering time: 0:00:02.793
   Simple:        yes
== yoke
Total rendering time: 0:00:09.147
   Simple:        yes
== head
Total rendering time: 0:00:08.912
   Simple:        yes
== head_lid
Total rendering time: 0:00:01.635
   Simple:        yes
```

</details>

**Tool: Bash** — Re-export STLs and preview PNGs with the fixed SCAD

```json
{
 "command": "rm -f stl/_*.png && bash render.sh 2>&1 | grep -E \"^==|WARN|ERR|done\"; ls -la stl",
 "timeout": 600000,
 "run_in_background": true
}
```

<details><summary>result</summary>

```
Command running in background with ID: b0i796say. Output is being written to: F:\TEMP\claude\F--turret2\a5ef03f6-cf40-4ca1-beaf-7fb67624334e\tasks\b0i796say.output. You will be notified when it completes. To check interim output, use Read on that file path.
```

</details>

**Tool: Write**

```json
{
 "file_path": "F:\\turret2\\README.md",
 "content": "# Tracking turret: XIAO ESP32S3 Sense pan/tilt\n\nCamera pan/tilt turret built around the Seeed Studio XIAO ESP32S3 Sense (OV2640, 8 MB PSRAM).\nTwo SG90/MG90S servos, on-device face detection (esp-dl) or motion detection, a proportional\ntracking loop with scan-when-lost, a laser/LED \"fire\" output, and a web UI with live MJPEG.\nEnclosure is parametric OpenSCAD (2021.01), five printed parts, no supports.\n\n```\nfirmware/    PlatformIO project (Arduino core 2.0.17, espressif32 6.13.0)\nhardware/    turret.scad, render scripts, stl/ output\n```\n\n![assembly](hardware/stl/assembly.png)\n\n## Bill of materials\n\n| Qty | Item | Notes |\n|----:|------|-------|\n| 1 | Seeed Studio XIAO ESP32S3 Sense | with the camera expansion board fitted |\n| 2 | SG90 or MG90S 9 g servo | MG90S (metal gear) recommended for pa\n... [7885 more chars]"
}
```

<details><summary>result</summary>

```
File created successfully at: F:\turret2\README.md (file state is current in your context — no need to Read it back)
```

</details>

**Tool: Write**

```json
{
 "file_path": "F:\\turret2\\.gitignore",
 "content": "firmware/.pio/\nfirmware/.vscode/\nfirmware/include/secrets.h\nfirmware/arduino/\nhardware/stl/*.stl\n"
}
```

<details><summary>result</summary>

```
File created successfully at: F:\turret2\.gitignore (file state is current in your context — no need to Read it back)
```

</details>

**Tool: Write**

```json
{
 "file_path": "C:\\Users\\User\\.claude\\projects\\F--turret2\\memory\\esp32s3-toolchains.md",
 "content": "---\nname: esp32s3-toolchains\ndescription: Which ESP32-S3 toolchains exist on this machine and which one has esp-dl face detection\nmetadata:\n  type: project\n---\n\nTwo ESP32 build chains are installed (verified 2026-09-10):\n- PlatformIO 6.1.18, `espressif32 @ 6.13.0` = arduino-esp32 2.0.17. Ships esp-dl\n  (`tools/sdk/esp32s3/ld/libhuman_face_detect.a`, `libdl.a`) and links them, so\n  `HumanFaceDetectMSR01/MNP01` work. Board id `seeed_xiao_esp32s3`.\n- Arduino IDE 2 with esp32 core 3.3.7; arduino-cli is not on PATH but lives at\n  `C:\\Users\\User\\AppData\\Local\\Programs\\Arduino IDE\\resources\\app\\lib\\backend\\resources\\arduino-cli.exe`.\n  FQBN `esp32:esp32:XIAO_ESP32S3:PSRAM=opi`. Core 3.x has NO esp-dl face models.\n- OpenSCAD 2021.01 CLI: `F:\\openscad-2021.01\\openscad.com` (headless PNG preview wor\n... [351 more chars]"
}
```

<details><summary>result</summary>

```
File created successfully at: C:\Users\User\.claude\projects\F--turret2\memory\esp32s3-toolchains.md
```

</details>

**Tool: Write**

```json
{
 "file_path": "C:\\Users\\User\\.claude\\projects\\F--turret2\\memory\\MEMORY.md",
 "content": "- [ESP32-S3 toolchains](esp32s3-toolchains.md) — PIO/arduino-esp32 2.0.17 has esp-dl face detect; Arduino 3.3.7 does not; arduino-cli path; OpenSCAD CLI path\n"
}
```

<details><summary>result</summary>

```
File created successfully at: C:\Users\User\.claude\projects\F--turret2\memory\MEMORY.md (file state is current in your context — no need to Read it back)
```

</details>

**Tool: Bash** — Show final render log, keep STLs tracked, list project files

```json
{
 "command": "cat \"/f/TEMP/claude/F--turret2/a5ef03f6-cf40-4ca1-beaf-7fb67624334e/tasks/b0i796say.output\" | grep -v \"^Compiling\\|^Parsing\\|^Saved\\|^Geometr\\|^CGAL\\|^Normal\\|^Simple\\|^Rendering\\|^ *Top\\|^ *Volume\\|^ *Vert\\|^ *Halfedge\\|^ *Edge\\|^ *Halffacet\\|^ *Facet\\|^Total\\|^   \" ; sed -i '/hardware\\/stl\\/\\*.stl/d' /f/turret2/.gitignore; find /f/turret2 -type f -not -path \"*/.pio/*\" -not -path \"*/arduino/*\" | sed 's|/f/turret2/||'"
}
```

**Tool: Read**

```json
{
 "file_path": "F:\\turret2\\hardware\\stl\\plate.png"
}
```

<details><summary>result</summary>

```
== base
== base_lid
== yoke
== head
== head_lid
== previews
done -> stl/
total 2788
drwxr-xr-x 1 User 197121      0 Sep 10 16:18 .
drwxr-xr-x 1 User 197121      0 Sep 10 16:13 ..
-rw-r--r-- 1 User 197121  53709 Sep 10 16:18 assembly.png
-rw-r--r-- 1 User 197121 608686 Sep 10 16:18 base.stl
-rw-r--r-- 1 User 197121 407024 Sep 10 16:18 base_lid.stl
-rw-r--r-- 1 User 197121 621113 Sep 10 16:18 head.stl
-rw-r--r-- 1 User 197121 203744 Sep 10 16:18 head_lid.stl
-rw-r--r-- 1 User 197121  63283 Sep 10 16:18 plate.png
-rw-r--r-- 1 User 197121 880469 Sep 10 16:18 yoke.stl

[exited with code 0]
.gitignore
firmware/.gitignore
firmware/include/camera_pins.h
firmware/include/config.h
firmware/include/secrets.h.example
firmware/make_arduino_sketch.ps1
firmware/platformio.ini
firmware/src/detector.cpp
firmware/src/detector.h
firmware/src/frame_store.h
firmware/src/index_html.h
firmware/src/main.cpp
firmware/src/servo_ctl.h
firmware/src/tracker.cpp
firmware/src/tracker.h
firmware/src/web.cpp
firmware/src/web.h
hardware/render.ps1
hardware/render.sh
hardware/stl/assembly.png
hardware/stl/base.stl
hardware/stl/base_lid.stl
hardware/stl/head.stl
hardware/stl/head_lid.stl
hardware/stl/plate.png
hardware/stl/yoke.stl
hardware/turret.scad
README.md
```

</details>

**Tool: Bash** — Widen the plate preview camera in both render scripts and re-render plate.png

```json
{
 "command": "sed -i 's|--camera=60,-120,160,60,50,0 --projection=p|--camera=45,-150,210,45,40,0 --projection=o|' render.sh render.ps1 && grep -c \"45,-150,210\" render.sh render.ps1 && /f/openscad-2021.01/openscad.com -o stl/plate.png --imgsize=1600,1100 --camera=45,-150,210,45,40,0 --projection=o --colorscheme=Tomorrow -D 'part=\"plate\"' turret.scad 2>&1 | grep -i -E \"warn|error\"; echo ok",
 "timeout": 120000
}
```

<details><summary>result</summary>

```
render.sh:1
render.ps1:1
ok
```

</details>

**Tool: Read**

```json
{
 "file_path": "F:\\turret2\\hardware\\stl\\plate.png"
}
```

**Tool: Bash** — Pull the plate preview camera back and re-render

```json
{
 "command": "sed -i 's|--camera=45,-150,210,45,40,0|--camera=45,-190,280,45,45,0|' render.sh render.ps1 && /f/openscad-2021.01/openscad.com -o stl/plate.png --imgsize=1600,1100 --camera=45,-190,280,45,45,0 --projection=o --colorscheme=Tomorrow -D 'part=\"plate\"' turret.scad 2>&1 | grep -i -E \"warn|error\"; echo ok",
 "timeout": 120000
}
```

<details><summary>result</summary>

```
ok
```

</details>

**Tool: Read**

```json
{
 "file_path": "F:\\turret2\\hardware\\stl\\plate.png"
}
```

## Claude  `16:20:16`

Project is complete at `F:\turret2`. Both build chains compile and all five parts export cleanly.

## What was built

**Firmware** (`firmware/`, PlatformIO, espressif32 6.13.0 = Arduino core 2.0.17)
- Camera at 240x240 RGB565; one detector task feeds face detection (esp-dl MSR01+MNP01, largest face) or motion detection (30x30 cell luma diff, centroid), draws the overlay, JPEG-encodes, publishes to a shared frame store.
- 50 Hz control task: proportional step per detection, slew-rate and smoothing limits, deadband, lock timer, scan sweep when the target is lost, motion suppression while servos move (so it doesn't chase its own pan).
- Web UI on :80 (mode buttons, click-to-aim, sliders for every gain, invert/trim, laser/auto-fire, save to NVS) and MJPEG on :81. STA with AP fallback (`turret`/`turret123`), mDNS `turret.local`.
- Pins: D0 pan, D1 tilt, D2 laser, D3 button; GPIO21 LED status.
- Build results: PlatformIO 1.53 MB flash, face detection linked. Arduino core 3.3.7 via `make_arduino_sketch.ps1` + arduino-cli also compiles (1.04 MB), with face mode compiled out because core 3.x has no esp-dl.

**Enclosure** (`hardware/turret.scad`, OpenSCAD 2021.01)
- Five parts: `base` (pan servo drops through the top plate, cable hole, power inlet, vents), `base_lid`, `yoke` (horn pocket with radial screw slots, arm A with through-mounted tilt servo, arm B with M3 pivot), `head` (board clamped between front pads and lid posts, camera window, horn pocket, USB-C slot, 6 mm laser saddle), `head_lid` (friction lip + 2x M2).
- All parametric; the servo envelope, board stack and clearances are the first 90 lines. `render.ps1` / `render.sh` regenerate `stl/*.stl` plus `assembly.png` and `plate.png`.

## Things to check before printing

- `cam_dz` (lens offset on the Sense board) and `stack_h` are my estimates of the Sense board stack, not measured. Measure your board and set them; the head has 0.8 mm width slack and a 10 mm window.
- `sv_horn_h` (3.8) sets the head-to-arm gap. Measure your horn hub.
- Servo direction signs are unknown until mounted; use the Invert toggles in the UI.
- The head's USB-C slot wants a right-angle cable; a straight plug hits the disc on down-tilt. Soldered power leads through the lid grommet is the cleaner option.

No `secrets.h` exists yet; copy `include/secrets.h.example` and fill in WiFi, or leave it and use the AP.

## User  `16:36:39`

these are the servos i will be using [Image #1]

## User  `16:36:39`

[Image: source: C:\Users\User\.claude\image-cache\a5ef03f6-cf40-4ca1-beaf-7fb67624334e\1.png]

**Tool: ToolSearch**

```json
{
 "query": "select:WebSearch,WebFetch",
 "max_results": 2
}
```

**Tool: WebSearch**

```json
{
 "query": "MG90S servo dimensions drawing mm flange hole spacing gear boss height horn"
}
```

**Tool: WebFetch**

```json
{
 "url": "https://www.electronicoscaldas.com/datasheet/MG90S_Tower-Pro.pdf",
 "prompt": "Extract every dimension in the mechanical drawing: body length, width, height, flange/mounting tab span, tab thickness, height from body bottom to tab, mounting hole spacing and diameter, output gear boss diameter and height, spline height, overall height, cable exit position. Quote exact numbers with units."
}
```

**Tool: WebFetch**

```json
{
 "url": "https://components101.com/motors/mg90s-metal-gear-servo-motor",
 "prompt": "Extract all mechanical dimensions given for the MG90S (body, mounting holes, height, shaft) and the description of included horns/arms. Quote numbers with units."
}
```

<details><summary>result</summary>

```
Web search results for query: "MG90S servo dimensions drawing mm flange hole spacing gear boss height horn"

Links: [{"title":"MG90S Horn Dimensions: A Comprehensive Guide for Hobbyists and Engineers","url":"https://www.aliexpress.com/s/wiki-ssr/article/mg90s-horn-dimensions"},{"title":"MG90S Micro Servo Specifications | PDF | Technology & Engineering","url":"https://www.scribd.com/doc/263826763/MG90S-Tower-Pro"},{"title":"MG90S servo spline size - adafruit industries","url":"https://forums.adafruit.com/viewtopic.php?t=95879"},{"title":"MG90S Metal Gear Servo","url":"https://hobbycomponents.com/motors-and-servos/835-mg90s-metal-gear-servo"},{"title":"Dimensions of MG90S metal servo (in mm) | Download Scientific Diagram","url":"https://www.researchgate.net/figure/Dimensions-of-MG90S-metal-servo-in-mm_fig2_365986320"},{"title":"MG90S Metal Gear Servo: Installation, Specs & Robotic - Zbotic","url":"https://zbotic.in/mg90s-metal-gear-servo-installation-specs-robotic-uses-in-india/"},{"title":"1365154 mg946r servo horn","url":"https://www.printables.com/model/1365154-mg946r-servo-horn"},{"title":"MG90S servo, Metal gear with Tiny and lightweight with high","url":"https://www.electronicoscaldas.com/datasheet/MG90S_Tower-Pro.pdf"},{"title":"people.ece.cornell.edu","url":"https://people.ece.cornell.edu/land/courses/ece4760/FinalProjects/f2017/kmv48_rp625/kmv48_rp625/kmv48_rp625/MG996RTowerPro.pdf"}]

Based on the search results, here's the information I found about MG90S servo dimens
... [866 more chars]
```

</details>

<details><summary>result</summary>

```
Based on the content provided, I cannot extract specific mechanical dimensions for the MG90S body, mounting holes, height, or shaft specifications. 

The page includes a "MG90S Dimensions" image, but the actual numerical values are not provided in the text content. The only dimension mentioned is the motor's weight: "13.4gm"

Regarding included accessories, the datasheet notes that the "Package includes gear horns and screws," though specific details about horn types or arm configurations are not described in the available text.

To obtain complete mechanical dimensions, you would need to consult the linked "MG90S Datasheet" PDF document directly.
```

</details>

<details><summary>result</summary>

```
I've reviewed the PDF content provided, but it appears to be a heavily compressed/encoded document that doesn't contain a mechanical drawing with the specific dimensions you're requesting.

The document seems to be primarily image-based (JPEG and flate-encoded content), and the extracted text doesn't reveal any mechanical specifications, measurements, or dimensional data for components like:

- Body length, width, height
- Flange/mounting tab specifications
- Mounting hole details
- Gear boss dimensions
- Cable exit positions

**To extract the mechanical dimensions you need, I would require:**

1. A clearer, text-searchable PDF version of the drawing
2. An image file of the mechanical drawing with visible dimension annotations
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

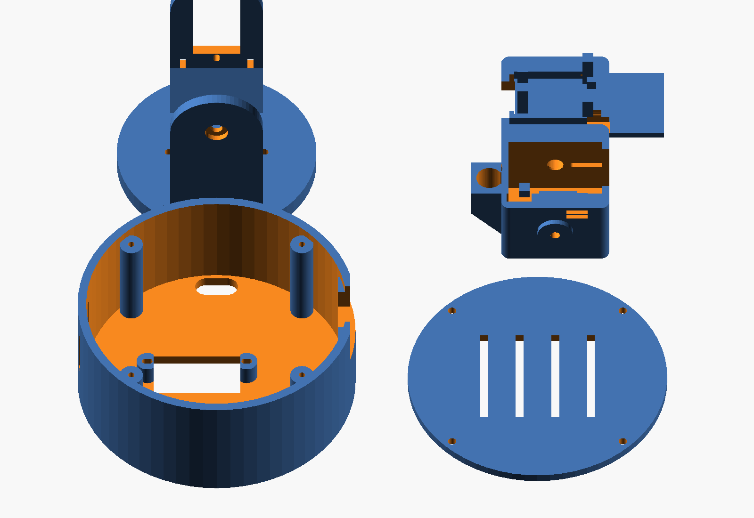
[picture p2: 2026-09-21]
hardware/stl/plate.png

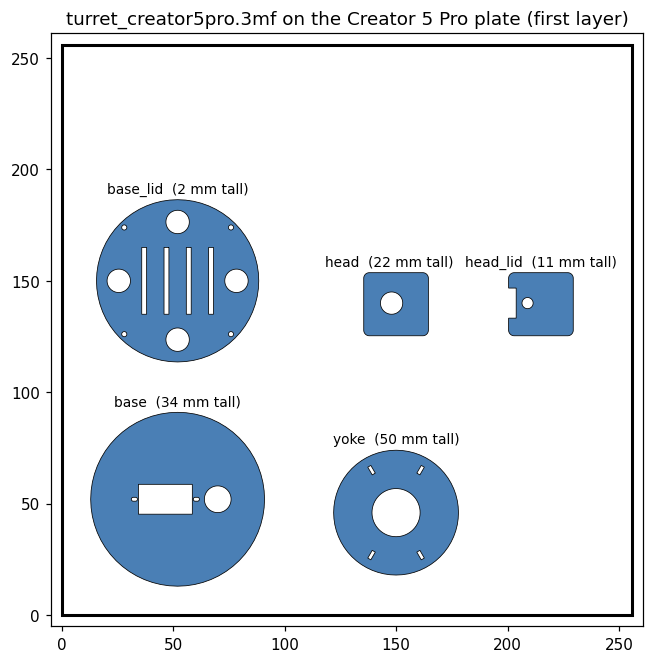
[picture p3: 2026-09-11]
hardware/turret_creator5pro_plate.png

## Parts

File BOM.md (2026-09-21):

# Bill of materials (excluding XIAO ESP32S3 Sense and MG90S servos)

Amazon links found 2026-09-10; listings change, so check quantity and specs before ordering.
Only the first six rows are required for a working turret; the rest are optional or convenience.

| # | Qty needed | Item | What it is for | Amazon |
|--:|---:|---|---|---|
| 1 | 1 kg | FLASHFORGE PETG Pro 1.75 mm, black | all five printed parts (73 g per set, so one spool covers many iterations). Use the `Flashforge PETG Pro @FF C5P` filament preset in Flash Studio for this spool; the project ships with `PETG Basic`, swap it in the filament dropdown | [B07Y9S22P5](https://www.amazon.com/FLASHFORGE-Filament-Dimensional-Mechanical-Waterproof/dp/B07Y9S22P5) |
| 2 | M2x8: 2 base lid, 2 head lid; M2x6: 2 head-to-single-arm horn (an 8 would reach the servo boss), 2 disc-to-double-arm horn; M2x4: 2 inlet board (servo ear screws come with the servos) | M2 flat-head self-tapping screw assortment, 800 pcs, 4 to 20 mm | every M2 pilot in the design is 1.75 mm for self-tapping M2 | [B0CY986CCR](https://www.amazon.com/Tapping-Woodworking-Fastener-Drilling-Assortment/dp/B0CY986CCR) |
| 3 | 1 | M3 x 8 button-head Torx screw, stainless | tilt pivot through arm B into the head; the 1.6 mm countersink in the arm is sized for a button head (5.7 dia x 1.65). 8 mm ends 0.35 mm short of the head cavity; a 12 mm would run 3.6 mm in and hit the XIAO edge | [B0GS115MXJ](https://www.amazon.com/dp/B0GS115MXJ) (the 12 mm version [B0GRZK17TZ](https://www.amazon.com/dp/B0GRZK17TZ) is too long for this design) |
| 4 | 1 (pack of 5) | 470 uF 16 V radial electrolytic capacitor, E-Projects | across servo 5 V / GND at the servo connector; stops brown-out resets when both servos start | [B07YN5MZBY](https://www.amazon.com/Projects-Radial-Electrolytic-Capacitor-470uF/dp/B07YN5MZBY) |
| 5 | 1 | 5 V 3 A USB-C power adapter, UL listed (Security-01) | main supply into the base inlet; 3 A covers two MG90S stalling plus the ESP32-S3 | [B09JW4QQJ2](https://www.amazon.com/Security-01-Supply-Adapter-Type-C-MLF-C060503000CU/dp/B09JW4QQJ2) |
| 6 | 1 (pack of 14) | Amabro USB-C panel-mount female socket breakout, 20.1 x 6.75 mm board, V/GND/D+/D-/CC pads, two mounting holes 16 mm apart | power inlet: screws to the flat facet on the OUTSIDE of the base's back (+X) wall with two M2x4 self-tapping screws (item 2), connector body through the 13 mm slot, board face flush with the wall so a plug reaches. Solder the 5 V and GND wires to the V and GND pads; only those two are needed | [B0H9S9C73Q](https://www.amazon.com/Amabro-Connector-Female-Socket-Breakout/dp/B0H9S9C73Q) |
| 7 | 1 kit | 22 AWG silicone stranded hookup wire, 6 colors (BINNEKER) | riser harness from the base up arm A to the head: 5 V, GND, pan and tilt signals (solder to the XIAO 5V, GND, D0, D1 pads; in through the floor USB-C slot), servo power splice in the base | [B07WYYDBZP](https://www.amazon.com/BINNEKER-Silicone-Resistant-Electronic-Stranded/dp/B07WYYDBZP) |
| 8 | 4 (pack of 100) | 10 x 3 mm clear self-adhesive rubber feet (Alamic) | base lid foot recesses are 10.5 mm dia x 0.8 mm deep | [B07JFGW1XC](https://www.amazon.com/Bumpers-Alamic-Adhesive-Transparent-Dampening/dp/B07JFGW1XC) |
| 9 | 1 (pack of 10), optional | 650 nm 5 V 5 mW red dot laser module, 6 mm brass barrel (HiLetgo) | "fire" indicator in the saddle on top of the head; fixed focus, ~20 mA at 5 V. Class 3R: not for pointing at faces. 6 mm barrel: set `laser_d = 6.3` before printing the head (default is 7.3 for item 9c) | [B071FT9HSV](https://www.amazon.com/HiLetgo-10pcs-650nm-Diode-Laser/dp/B071FT9HSV) |
| 9b | 1 (pack of 3), optional | 650 nm 1 mW Class 2 mini dot module, 3 V, 6 x 10 mm (alternative to 9) | same 6 mm barrel, eye-safe class for a turret that points at people; run it from the 3V3 pin through the transistor below (<40 mA) | [B082CRKW5Z](https://www.amazon.com/Mini-Type-650nm-6x10mm-Module-Driver/dp/B082CRKW5Z) |
| 9c | 1, optional | Quarton VLM-650-03 LPT, Class 2 <1 mW, APC driver, 2.6 to 6 V, 7 x 21 mm | the quality option (regulated driver, made in Taiwan); 7 mm barrel. The head is printed for this module (`laser_d = 7.3` default since 2026-09-19) | [B00ZR80S9S](https://us.amazon.com/Quarton-Laser-Module-VLM-650-03-ECONOMICAL/dp/B00ZR80S9S) |
| 9d | 1 (pack of 100) | 2N2222 NPN transistor, TO-92 | laser driver: GPIO3 -> 1 k -> base, emitter to GND, laser (-) to collector, laser (+) to 5V (or 3V3 for 9b). Keeps the module's 20 to 40 mA off the ESP32 pin | [B07222XY81](https://www.amazon.com/2N2222-Plastic-Encapsulate-Power-Transistors-600mA/dp/B07222XY81) |
| 10 | 1 (pack of 6), optional | 12 mm momentary push button, pre-wired, panel mount (DaierTek) | trigger button on D3 (GPIO4) to GND; toggles the laser. Needs a 12 mm hole in the base wall (not in the CAD; add one or skip) | [B0C8HM4T24](https://www.amazon.com/DaierTek-Momentary-Button-Switch-Waterproof/dp/B0C8HM4T24) |
| 11 | 1 (2-pack), optional | Right-angle USB-C to USB-A cable, 1 ft (SUNGUY) | flashing/serial with the board in the head; the head floor slot takes a right-angle plug that runs backward. Not needed if you pull the lid to flash | [B0784F9JP2](https://www.amazon.com/SUNGUY-Braided-Charging-Samsung-OnePlus/dp/B0784F9JP2) |

## Not needed

- Servo horns and horn screws: included with the MG90S 4-pack (single, double and cross arms).
- Resistors for the laser: the 5 V modules have their own current limiting; the transistor is only there to keep 20 mA off the GPIO.
- Rubber feet adhesive, nuts, washers: none used.

## Notes

- Item 6 alternative: any USB-C female breakout with solder pads works; a 5 V barrel jack also fits the same notch (13 x 11.5 mm) if you prefer a wall-wart with a barrel plug.
- Item 2 alternative if you want machine screws instead of self-tapping: heat-set inserts are not designed in; the pilots are plain 1.75 mm holes.
- If you print PLA instead, any 1.75 mm PLA works with the `Flashforge PLA Basic @FF C5P` preset.

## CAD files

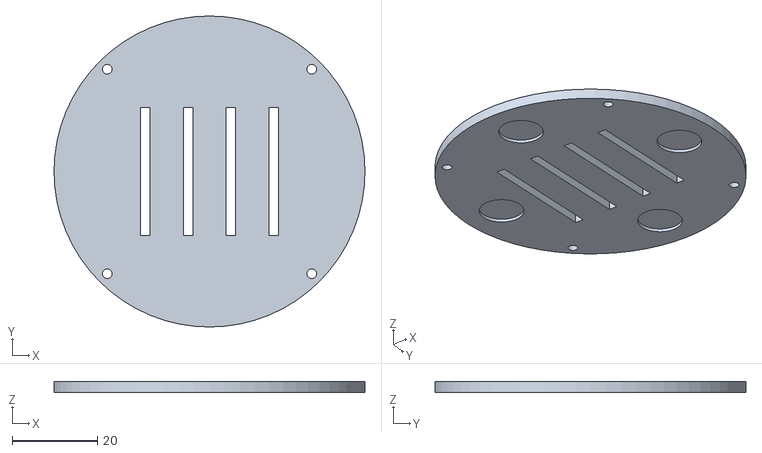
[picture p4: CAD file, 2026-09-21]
hardware/stl/base_lid.stl
72.8 x 72.8 x 2.50

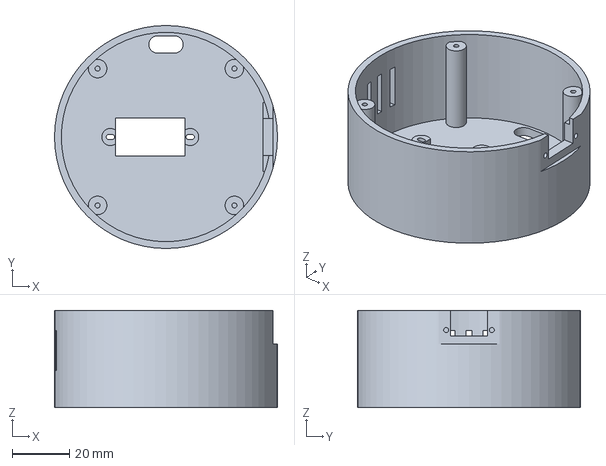
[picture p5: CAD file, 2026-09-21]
hardware/turret_creator5pro_base.3mf
78.0 x 78.0 x 34.0 mm

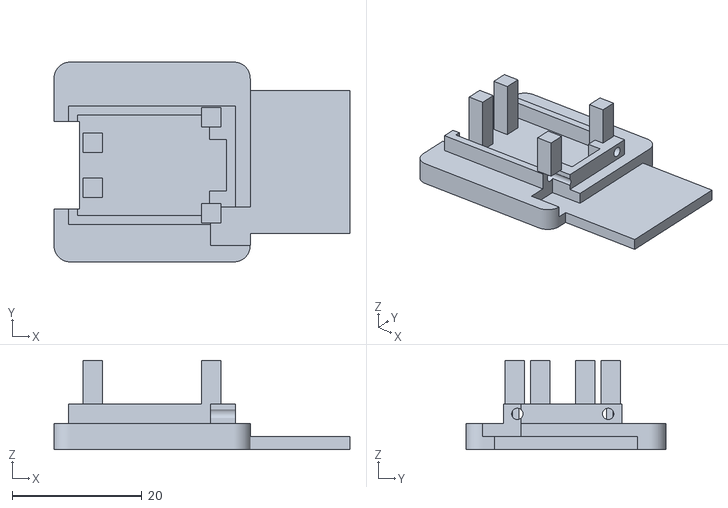
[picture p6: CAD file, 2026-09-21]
hardware/stl/head_lid.stl
45.6 x 30.8 x 13.7

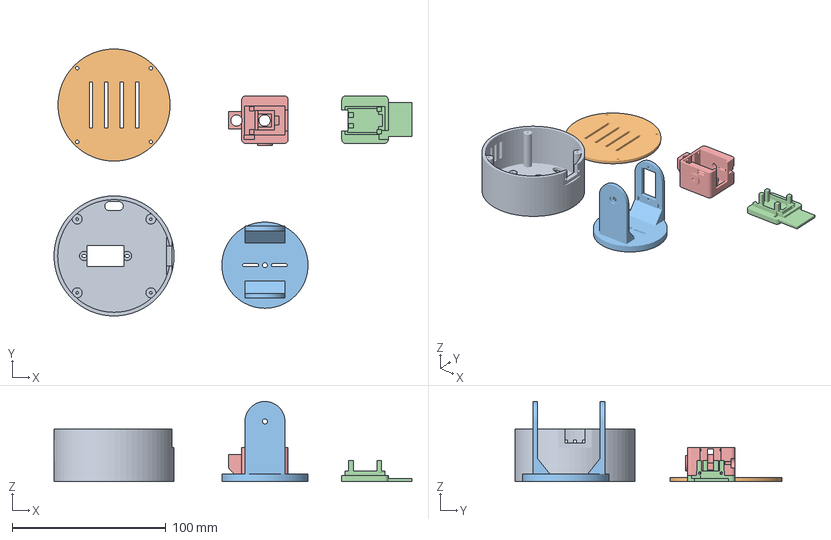
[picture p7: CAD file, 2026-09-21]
hardware/turret_creator5pro.3mf
232.5 x 173.4 x 52.0 mm
base.stl
base_lid.stl
yoke.stl
head_lid.stl
head.stl

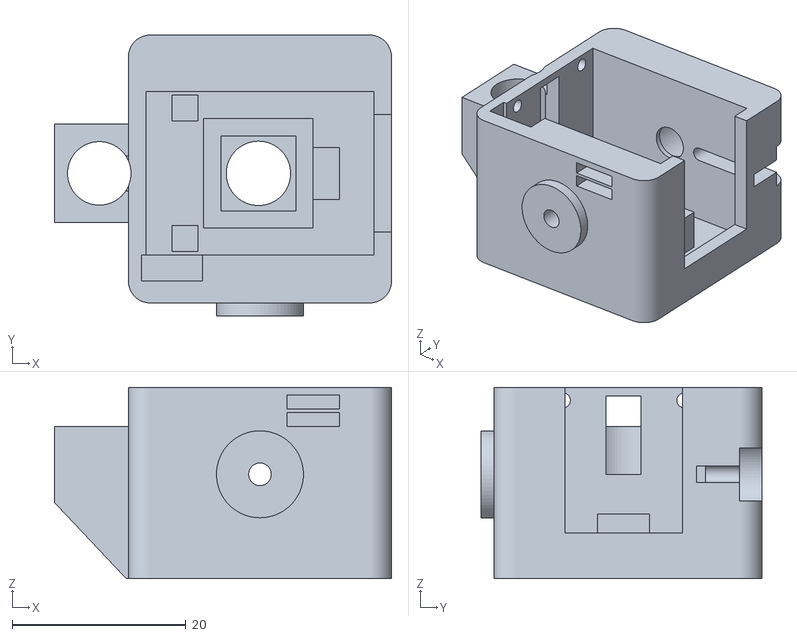
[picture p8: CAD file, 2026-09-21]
hardware/stl/head.stl
38.8 x 32.3 x 22.0

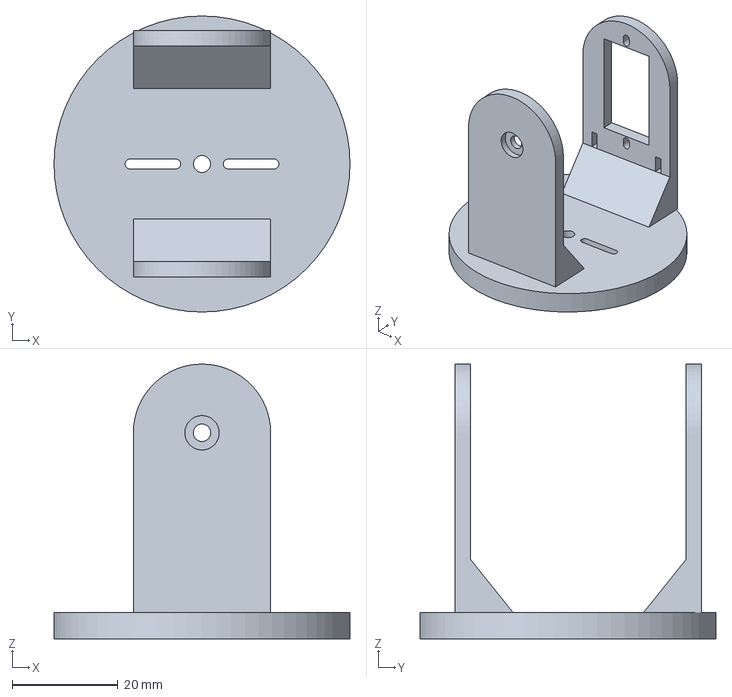
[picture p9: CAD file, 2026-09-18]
hardware/turret_creator5pro_yoke.3mf
56.0 x 56.0 x 52.0 mm

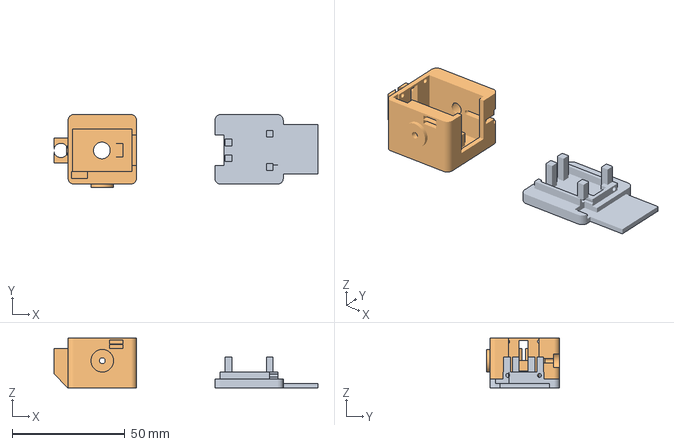
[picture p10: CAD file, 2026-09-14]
hardware/turret_creator5pro_head_head_lid.3mf
116.9 x 32.3 x 22.0 mm
head_lid.stl
head.stl

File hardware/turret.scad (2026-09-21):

// =============================================================================
//  Tracking turret enclosure for Seeed Studio XIAO ESP32S3 Sense + 2x MG90S (SupSeek)
//  OpenSCAD 2021.01
//
//  Parts (select with -D part="<name>"):
//    base       pan servo housing, open bottom
//    base_lid   bottom cover for the base (4x M2 screws, rubber-foot recesses)
//    yoke       pan platform: disc on the pan horn + two arms carrying the tilt axis
//    head       camera housing for the XIAO + Sense board (open back)
//    head_lid   back cover for the head (friction lip + 2x M2)
//    assembly   everything in place with mock servos / board, for preview
//    plate      all printable parts laid out flat
//
//  Coordinate convention (assembly): Z up, camera window on the -X face (camera looks along -X).
//  Every part module is authored in assembly position; print_* transforms
//  reorient for the bed. Dimensions in mm.
// =============================================================================

part = "assembly";          // base | base_lid | yoke | head | head_lid | assembly | plate
$fn = 64;

// ---------------------------------------------------------------- tolerances
clr      = 0.30;            // general clearance around inserted parts
lip_clr  = 0.25;            // friction-fit lip clearance
m2_pilot = 1.75;            // M2 self-tapping pilot hole in PLA/PETG
m2_free  = 2.30;            // M2 through hole
m3_pilot = 2.60;
m3_free  = 3.30;

// ------------------------------------------------------------- MG90S servo
// Target servo: MG90S (SupSeek 4-pack, TowerPro-compatible). TowerPro config table:
// A 32.5 (ear span), B 22.8 (body), C 28.4 (bottom to spline top), D 12.4 (width),
// F 18.5 (bottom to ear top). Clones run up to 23.9 x 12.7, so the body cut below is
// deliberately loose; the ear screws locate the servo.
// Local servo frame: shaft axis = +Z through (0,0); Z=0 at flange BOTTOM face.
sv_l        = 22.8;         // body length (along local X)
sv_w        = 12.4;         // body width  (along local Y)
sv_cut_l    = 23.6;         // body through-cut envelope before clearance (covers clones)
sv_cut_w    = 12.8;
sv_h        = 22.7;         // body height, bottom of body to top of body (below the boss)
sv_flange_z = 16.0;         // body bottom to flange bottom (F 18.5 - flange_t)
sv_flange_t = 2.5;
sv_flange_l = 32.5;         // MEASURED 32.2 (H)
sv_hole_d   = 2.0;
sv_hole_sp  = 27.9;         // MEASURED 27.8 / 28.0; pilots are slotted +-0.6 (27.3 .. 28.5)
sv_shaft_off= 5.9;          // shaft axis from the near body end (along X)
sv_boss_d   = 12.0;         // round gear-head boss; must be < sv_cut_w + 2*clr to pass the arm
sv_boss_h   = 3.2;          // MEASURED K (ear top -> boss top) 7.3 / 7.5: 4.2 body above ears + 3.2
sv_spline_d = 4.8;          // 20T spline
sv_spline_h = 3.2;
// Horns (MEASURED on the kit, 2026-09-11). The cross horn is asymmetric (~31 mm long axis) and
// does not fit the head, so the head uses the SINGLE arm (vertical, pointing down) and the pan
// disc the DOUBLE arm. Each horn seats differently on the spline, so hub heights are per horn.
sv_hub_d    = 6.8;          // hub outer diameter (both horns)
sv_horn_t   = 2.0;          // arm plate thickness (E)
sv_arm_w    = 5.1;          // arm width (D)
sv_single_l = 18.0;         // single arm, hub center -> tip (C)
sv_double_l = 31.2;         // double arm, tip -> tip (J)
sv_horn_h_s = 3.8;          // single arm: boss top -> outer face of the arm plate (A1s)
sv_hub_top_s= 6.4;          // single arm: boss top -> top of the hub (A2s), 2.6 proud of the arm
sv_horn_h_d = 5.85;         // double arm: boss top -> outer face of the arm plate (A1)
sv_hub_top_d= 6.26;         // double arm: boss top -> top of the hub (A2), 0.41 proud of the arm
gap_margin  = 0.8;          // extra head-to-arm clearance; a short hub seat beats a rubbing head
sv_seat_extra_s = 2.0;      // AS ASSEMBLED 2026-09-17: the single-arm horn sits 2 mm higher on the tilt servo's
                            // spline than the bench-measured hub height, so the whole head is 2 mm further
                            // from arm A. Goes into gap_a only; the horn itself (and the head's pocket and
                            // hub counterbore) is unchanged.
sv_cx       = sv_shaft_off - sv_l/2;            // body center X in the local frame (-5.5)
sv_top      = sv_h - sv_flange_z;               // body top above flange bottom (6.7)
sv_boss_top = sv_top + sv_boss_h;               // 9.2
sv_horn_face= sv_boss_top + sv_horn_h_d;        // double arm outer face above the flange bottom (pan)
horn_pocket = sv_horn_t + 0.6;                  // recess depth for the horn arm plate (2.6)
hub_relief_s= horn_pocket + (sv_hub_top_s - sv_horn_h_s) + 0.6;  // head counterbore for the single-arm hub (5.8)
hub_relief_d= horn_pocket + (sv_hub_top_d - sv_horn_h_d) + 0.6;  // disc counterbore for the double-arm hub (3.6)
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

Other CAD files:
hardware/turret_creator5pro_head.3mf
hardware/stl/base.stl
hardware/stl/yoke.stl

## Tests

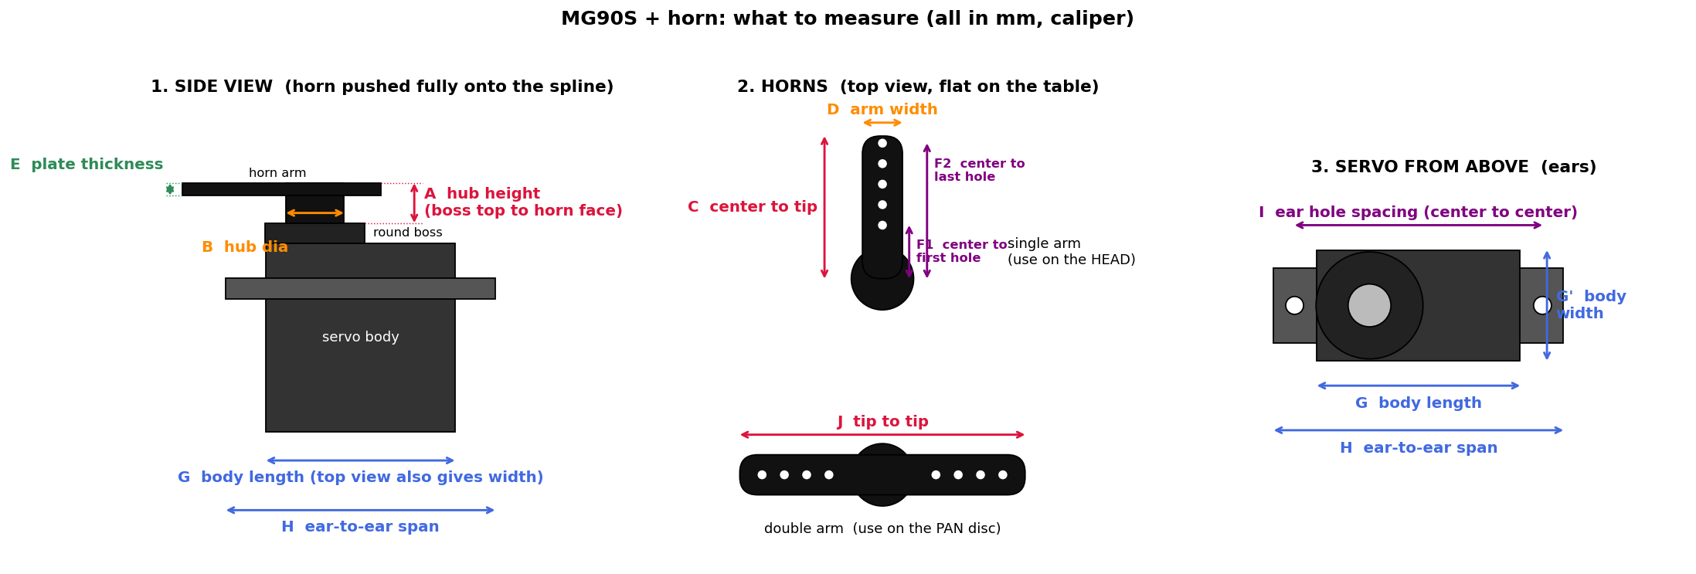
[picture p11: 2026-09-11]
docs/measure_servo_horn.png

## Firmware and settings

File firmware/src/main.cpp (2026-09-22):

// Tracking turret: Seeed Studio XIAO ESP32S3 Sense + 2x SG90/MG90S pan-tilt.
//
// Tasks:
//   detectorTask (core 1): grab RGB565 240x240 frame -> face (esp-dl) or motion
//                          detection -> feed tracker -> draw overlay -> JPEG -> FrameStore
//   controlTask  (core 1): 50 Hz servo slew / scan / laser
//   httpd (core 0):        :80 UI + JSON + control, :81 MJPEG stream
//   loop():                status LED, trigger button

#include <Arduino.h>
#include <WiFi.h>
#include <ESPmDNS.h>
#include "esp_system.h"
#include "esp_log.h"
#include "esp_camera.h"
#include "img_converters.h"
#if defined(__has_include)
#if __has_include("fb_gfx.h")
#include "fb_gfx.h"
#define HAVE_FB_GFX 1
#endif
#endif
#ifndef HAVE_FB_GFX
#define HAVE_FB_GFX 0
// Minimal stand-in so the overlay compiles without the fb_gfx component: same field names,
// RGB565 only, 0x00BBGGRR color like fb_gfx, no text.
typedef enum { FB_RGB888, FB_BGR888, FB_RGB565, FB_BGR565, FB_GRAY } fb_format_t;
typedef struct { int width; int height; int bytes_per_pixel; fb_format_t format; uint8_t* data; } fb_data_t;
static inline void fbPix(fb_data_t* g, int x, int y, uint32_t c) {
  uint8_t r = c & 0xFF, gr = (c >> 8) & 0xFF, b = (c >> 16) & 0xFF;
  uint16_t v = ((r >> 3) << 11) | ((gr >> 2) << 5) | (b >> 3);
  uint8_t* p = g->data + (y * g->width + x) * 2;
  p[0] = v >> 8; p[1] = v & 0xFF;
}
static void fb_gfx_drawFastHLine(fb_data_t* g, int32_t x, int32_t y, int32_t w, uint32_t c) { for (int i = 0; i < w; i++) fbPix(g, x + i, y, c); }
static void fb_gfx_drawFastVLine(fb_data_t* g, int32_t x, int32_t y, int32_t h, uint32_t c) { for (int i = 0; i < h; i++) fbPix(g, x, y + i, c); }
static void fb_gfx_fillRect(fb_data_t* g, int32_t x, int32_t y, int32_t w, int32_t h, uint32_t c) { for (int j = 0; j < h; j++) fb_gfx_drawFastHLine(g, x, y + j, w, c); }
static uint32_t fb_gfx_print(fb_data_t*, int32_t, int32_t, uint32_t, const char*) { return 0; }
#endif
#include "config.h"
#include "camera_pins.h"
#include "detector.h"
#include "color_tracker.h"
#include "tracker.h"
#include "frame_store.h"
#include "web.h"
#include "display.h"

static Detector detector;
static ColorTracker torso;
static Tracker tracker;
static Target lastFace;          // most recent face detection, for the overlay
static FrameStore frames;
static Stats stats;
static bool apMode = false;
static String netInfo;

#define COLOR_WHITE  0x00FFFFFF
#define COLOR_RED    0x000000FF
#define COLOR_GREEN  0x0000FF00
#define COLOR_YELLOW 0x0000FFFF
#define COLOR_CYAN   0x00FFFF00
#define COLOR_MAGENTA 0x00FF00FF

// IDF-component log sink. The esp32-camera driver task (cam_task) runs on a 2 KB stack in
// this SDK build. Its "EV-VSYNC-OVF" message is routed by the esp_diagnostics log wrappers
// into esp_log_writev -> vprintf -> stdio -> newlib lock creation, which overflowed that
// stack (panic observed and decoded from the backtrace). esp_log_level_set() does not stop
// it, so the IDF log vprintf is replaced with a no-op. The short "cam_hal: EV-VSYNC-OVF"
// line still appears on the console via the ROM printf path; that one is harmless.
// Everything this firmware prints itself goes through Serial and is unaffected.
static int idfLogSink(const char*, va_list) { return 0; }

static bool cameraInit() {
  esp_log_set_vprintf(idfLogSink);

  camera_config_t c = {};
  c.ledc_channel = LEDC_CHANNEL_0;
  c.ledc_timer = LEDC_TIMER_0;
  c.pin_d0 = Y2_GPIO_NUM;
  c.pin_d1 = Y3_GPIO_NUM;
  c.pin_d2 = Y4_GPIO_NUM;
  c.pin_d3 = Y5_GPIO_NUM;
  c.pin_d4 = Y6_GPIO_NUM;
  c.pin_d5 = Y7_GPIO_NUM;
  c.pin_d6 = Y8_GPIO_NUM;
  c.pin_d7 = Y9_GPIO_NUM;
  c.pin_xclk = XCLK_GPIO_NUM;
  c.pin_pclk = PCLK_GPIO_NUM;
  c.pin_vsync = VSYNC_GPIO_NUM;
  c.pin_href = HREF_GPIO_NUM;
  c.pin_sccb_sda = SIOD_GPIO_NUM;
  c.pin_sccb_scl = SIOC_GPIO_NUM;
  c.pin_pwdn = PWDN_GPIO_NUM;
  c.pin_reset = RESET_GPIO_NUM;
  c.xclk_freq_hz = CAM_XCLK_HZ;
  c.pixel_format = PIXFORMAT_RGB565;   // raw pixels for esp-dl and motion detection
  c.frame_size = CAM_FRAMESIZE;
  c.jpeg_quality = 12;
  c.fb_count = 3;                      // one held by the detector, two for the driver to cycle
  c.fb_location = CAMERA_FB_IN_PSRAM;
  c.grab_mode = CAMERA_GRAB_LATEST;

  esp_err_t err = esp_camera_init(&c);
  if (err != ESP_OK) {
    Serial.printf("camera init failed 0x%x\n", err);
    return false;
  }
  sensor_t* s = esp_camera_sensor_get();
  if (s) {
    s->set_framesize(s, CAM_FRAMESIZE);
    s->set_hmirror(s, tracker.settings.hmirror ? 1 : 0);
    s->set_vflip(s, tracker.settings.vflip ? 1 : 0);
    s->set_brightness(s, 0);
    s->set_saturation(s, 0);
  }
  return true;
}

// fb_gfx has no bounds checking: a negative or oversized coordinate writes outside the
// frame buffer and corrupts the heap (observed: StoreProhibited in tlsf_malloc after a face
// near the top edge). Everything drawn on the frame goes through these clipped helpers.
static inline void gfxH(fb_data_t* g, int x, int y, int w, uint32_t c) {
  if (y < 0 || y >= g->height) return;
  if (x < 0) { w += x; x = 0; }
  if (x + w > g->width) w = g->width - x;
  if (w > 0) fb_gfx_drawFastHLine(g, x, y, w, c);
}
static inline void gfxV(fb_data_t* g, int x, int y, int h, uint32_t c) {
  if (x < 0 || x >= g->width) return;
  if (h < 0) { y += h; h = -h; }
  if (y < 0) { h += y; y = 0; }
  if (y + h > g->height) h = g->height - y;
  if (h > 0) fb_gfx_drawFastVLine(g, x, y, h, c);
}
static inline void gfxFill(fb_data_t* g, int x, int y, int w, int h, uint32_t c) {
  if (x < 0) { w += x; x = 0; }
  if (y < 0) { h += y; y = 0; }
  if (x + w > g->width) w = g->width - x;
  if (y + h > g->height) h = g->height - y;
  if (w > 0 && h > 0) fb_gfx_fillRect(g, x, y, w, h, c);
}
// fb_gfx text is FreeMonoBold 12pt: 14 px advance per character, glyphs drawn downward from
// y over up to 24 rows. Refuse anything that would leave the frame.
static inline void gfxText(fb_data_t* g, int x, int y, uint32_t c, const char* s) {
  int w = 14 * (int)strlen(s);
  if (x < 0 || y < 0 || x + w > g->width || y + 24 > g->height) return;
  fb_gfx_print(g, x, y, c, s);
}
static inline void gfxBox(fb_data_t* g, int cx, int cy, int w, int h, uint32_t c) {
  int x = cx - w / 2, y = cy - h / 2;
  gfxH(g, x, y, w, c);
  gfxH(g, x, y + h - 1, w, c);
  gfxV(g, x, y, h, c);
  gfxV(g, x + w - 1, y, h, c);
}

static void drawOverlay(camera_fb_t* fb, const Target& t) {
  fb_data_t g;
  g.width = fb->width;
  g.height = fb->height;
  g.data = fb->buf;
  g.bytes_per_pixel = 2;
  g.format = FB_RGB565;

  // crosshair + deadband
  int cx = fb->width / 2, cy = fb->height / 2;
  gfxH(&g, cx - 10, cy, 21, COLOR_WHITE);
  gfxV(&g, cx, cy - 10, 21, COLOR_WHITE);
  int db = tracker.settings.deadbandPx;
  if (db > 0) gfxBox(&g, cx, cy, 2 * db, 2 * db, COLOR_WHITE);

  // last detected face stays on screen (green) while the torso tracker carries the target
  if (t.found && t.kind == TARGET_TORSO && lastFace.found) {
    // green = face detector (esp-dl 1.x), magenta = whole-body detector (ESPDet-Pico)
    uint32_t seedColor = lastFace.kind == TARGET_PERSON ? COLOR_MAGENTA : COLOR_GREEN;
    gfxBox(&g, lastFace.x, lastFace.y, lastFace.w, lastFace.h, seedColor);
    char s[24];
    snprintf(s, sizeof(s), "%s %lums", lastFace.kind == TARGET_PERSON ? "body" : "face",
             (unsigned long)(millis() - tracker.lastFaceMs));
    gfxText(&g, 4, 30, seedColor, s);                // second text row, below SCAN
  }
  if (t.found) {
    uint32_t color = tracker.locked() ? COLOR_RED
                     : (t.kind == TARGET_FACE ? COLOR_GREEN
                        : (t.kind == TARGET_PERSON ? COLOR_MAGENTA
                           : (t.kind == TARGET_TORSO ? COLOR_CYAN : COLOR_YELLOW)));
    gfxBox(&g, t.x, t.y, t.w, t.h, color);
    gfxFill(&g, t.x - 2, t.y - 2, 5, 5, color);
    int ax, ay;
    if (tracker.aimPoint(ax, ay) && ay != t.y) {
      gfxH(&g, ax - 6, ay, 13, color);                // aim point (offset from the face center)
      gfxV(&g, ax, ay - 6, 13, color);
      gfxV(&g, t.x, t.y, ay - t.y, color);            // tether to the face center
    }
  }
  if (tracker.scanning()) gfxText(&g, 4, 4, COLOR_YELLOW, "SCAN");
  if (tracker.locked()) gfxText(&g, fb->width - 14 * 4 - 4, 4, COLOR_RED, "LOCK");
}

// Person mode: the face detector acquires (and periodically re-anchors) the target, the
// color tracker follows the torso in between, so the person can turn or walk sideways.
// A new track needs two detections within this long of each other. A lamp glare that the person
// model scores once at 0.5 does not repeat on the next frame; a person does.
static const uint32_t CONFIRM_WINDOW_MS = 900;

static Target personPipeline(camera_fb_t* fb, uint32_t now) {
  static uint32_t lastFaceRun = 0;
  static uint32_t pendingMs = 0;         // time of an unconfirmed first detection (0 = none)
  static float winX = -1, winY = -1;     // last torso window center, for the stuck-window check
  static uint32_t winMoveMs = 0;
  const Settings& s = tracker.settings;
  torso.minConfidence = s.torsoMinConf;

  if (!s.torsoTrack) {
    torso.reset();
#if HAVE_ESPDET
    Target f = personDetect(fb, s.personThr);
#else
    Target f = detector.detectFace(fb);
#endif
    lastFace = f;
    return f;
  }

  bool runFace = !torso.active() || (now - lastFaceRun) >= (uint32_t)s.redetectMs;
  Target face;
  if (runFace) {
#if HAVE_ESPDET
    face = personDetect(fb, s.personThr);       // whole-body box; "face" name kept for the flow below
#else
    face = detector.detectFace(fb);
#endif
    lastFaceRun = now;
  }

  if (face.found && !torso.active()) {
    // Item 2 gates, only for starting a NEW track (a live track is refreshed by every detection):
    // (a) a box wholly in the top quarter of the frame while tilt is already at its tracking ceiling
    //     is a ceiling fixture, not a person;
    // (b) the first detection only arms; the second within CONFIRM_WINDOW_MS confirms.
    bool topOnly = (face.y + face.h / 2) < CAM_H / 4 && tracker.tiltSet() >= s.trackTiltMax - 1.0f;
    if (topOnly) {
      face = Target();
      pendingMs = 0;
    } else if (!pendingMs || (now - pendingMs) > CONFIRM_WINDOW_MS) {
      pendingMs = now;                   // armed; report nothing yet
      face = Target();
    } else {
      pendingMs = 0;                     // confirmed
    }
  }

  if (face.found) {
    lastFace = face;
    tracker.lastFaceMs = now;
    winX = winY = -1;
    int tw, th, tcx, tcy;
    float aimY;
    if (face.kind == TARGET_PERSON) {
      // Body box: seed the color tracker on the upper torso (below the head, above the waist).
      int top = face.y - face.h / 2;
      tw = (int)(face.w * 0.8f);
      th = (int)(face.h * 0.35f);
      tcx = face.x;
      tcy = top + (int)(face.h * 0.20f) + th / 2;
      aimY = top + s.aimFrac * face.h;
    } else {
      // Face box: torso 1.6 face widths wide, 1.4 face heights tall, starting half a face below the chin.
      tw = (int)(face.w * 1.6f);
      th = (int)(face.h * 1.4f);
      tcx = face.x;
      tcy = face.y + face.h + th / 2;
      aimY = face.y + s.aimBelow * face.w;
    }
    if (tcy + th / 2 > fb->height) tcy = fb->height - th / 2;
    if (tcy - th / 2 < 0) tcy = th / 2;
    // Aim point relative to the torso center, in torso heights, so it rides along with the blob.
    float aimRel = th > 0 ? (aimY - tcy) / (float)th : 0;
    if (th >= 8 && tw >= 8) torso.refresh(fb, tcx, tcy, tw, th, aimRel, torso.active() ? 0.3f : 1.0f);
    tracker.torsoAimY = -1;
    return face;
  }

  Target t;
  // A color track that no face has confirmed for faceTimeoutMs is more likely background
  // than a person who turned away; drop it and wait for the next face.
  if (torso.active() && tracker.lastFaceMs && (now - tracker.lastFaceMs) > (uint32_t)s.faceTimeoutMs) {
    torso.reset();
    lastFace = Target();
    tracker.lastFaceMs = 0;
    tracker.torsoAimY = -1;
    return t;
  }
  if (torso.active() && torso.track(fb, t)) {
    // Item 3b: a window that has not moved for a second while the servos are still slewing is
    // tracking nothing (a uniform wall or ceiling moves with the camera). Drop it.
    if (winX < 0 || fabsf(t.x - winX) + fabsf(t.y - winY) > 3.0f) {
      winX = t.x; winY = t.y; winMoveMs = now;
    } else if (tracker.moving() && (now - winMoveMs) > 1000) {
      torso.reset();
      lastFace = Target();
      tracker.lastFaceMs = 0;
      tracker.torsoAimY = -1;
      winX = winY = -1;
      return Target();
    }
    tracker.torsoAimY = torso.aimY();
    return t;
  }
  tracker.torsoAimY = -1;
  if (!tracker.targetFresh(now)) {
    torso.reset();            // give up after lostMs; the next face starts a new track
    lastFace = Target();
    tracker.lastFaceMs = 0;
  }
  return t;
}

static void detectorTask(void*) {
  uint32_t fpsWindowStart = millis();
  int fpsFrames = 0;
  Mode prevMode = tracker.mode();

  // Work on a private copy of each frame and hand the driver's buffer back immediately
  // (a 115 KB PSRAM memcpy, ~2 ms). Detection can then take as long as it likes without
  // starving the camera DMA, which is what triggered the driver's overflow path.
  // Guard bands around the work frame: an overlay slip lands in unused PSRAM, not a heap header.
  const size_t GUARD = 8192;
  camera_fb_t work = {};
  uint8_t* raw_buf = (uint8_t*)ps_malloc(CAM_W * CAM_H * 2 + 2 * GUARD);
  work.buf = raw_buf ? raw_buf + GUARD : nullptr;
  if (!work.buf) {
    Serial.println("[turret] no PSRAM for the work frame");
    vTaskDelete(nullptr);
    return;
  }

  for (;;) {
    camera_fb_t* raw = esp_camera_fb_get();
    if (!raw) {
      vTaskDelay(pdMS_TO_TICKS(10));
      continue;
    }
    uint32_t t0 = millis();
    if (raw->format != PIXFORMAT_RGB565 || raw->len > (size_t)(CAM_W * CAM_H * 2)) {
      esp_camera_fb_return(raw);
      continue;
    }
    memcpy(work.buf, raw->buf, raw->len);
    work.len = raw->len;
    work.width = raw->width;
    work.height = raw->height;
    work.format = raw->format;
    work.timestamp = raw->timestamp;
    esp_camera_fb_return(raw);
    camera_fb_t* fb = &work;
    Mode mode = tracker.mode();
    if (mode != prevMode) {
      detector.resetMotion();
      torso.reset();
      lastFace = Target();
      tracker.lastFaceMs = 0;
      prevMode = mode;
    }

    Target t;
    if (mode == MODE_FACE) {
      t = personPipeline(fb, t0);
    } else if (mode == MODE_MOTION) {
      bool suppress = tracker.moving() || tracker.msSinceMove(t0) < (uint32_t)tracker.settings.settleMs;
      t = detector.detectMotion(fb, suppress, tracker.settings.motionThr, tracker.settings.motionMinCells);
    }
    stats.inferMs = millis() - t0;
    if (mode == MODE_FACE || mode == MODE_MOTION) tracker.onDetection(t, millis());

    drawOverlay(fb, t);

    uint8_t* jpg = nullptr;
    size_t len = 0;
    if (frame2jpg(fb, tracker.settings.jpegQuality, &jpg, &len)) {
      frames.publish(jpg, len);
    }

    fpsFrames++;
    uint32_t now = millis();
    if (now - fpsWindowStart >= 1000) {
      stats.fps = fpsFrames * 1000.0f / (now - fpsWindowStart);
      fpsFrames = 0;
      fpsWindowStart = now;
    }
    stats.frameMs = now - t0;
    if (mode == MODE_MANUAL || mode == MODE_SCAN) vTaskDelay(pdMS_TO_TICKS(40));  // cap ~20 fps
    else taskYIELD();
  }
}

static void controlTask(void*) {
  TickType_t last = xTaskGetTickCount();
  const TickType_t period = pdMS_TO_TICKS(1000 / CONTROL_HZ);
  for (;;) {
    vTaskDelayUntil(&last, period);
    tracker.tick(millis());
  }
}

static void wifiBegin() {
  WiFi.persistent(false);
  if (strlen(WIFI_SSID) > 0) {
    WiFi.mode(WIFI_STA);
    WiFi.setHostname(HOSTNAME);
    WiFi.setSleep(false);
    WiFi.begin(WIFI_SSID, WIFI_PASS);
    Serial.printf("WiFi: connecting to %s", WIFI_SSID);
    uint32_t t0 = millis();
    while (WiFi.status() != WL_CONNECTED && millis() - t0 < WIFI_CONNECT_MS) {
      digitalWrite(PIN_STATUS_LED, (millis() / 100) & 1);
      delay(50);
      if ((millis() / 500) % 2 == 0) Serial.print('.');
    }
    Serial.println();
  }
  if (WiFi.status() != WL_CONNECTED) {
    apMode = true;
    WiFi.mode(WIFI_AP);
    WiFi.softAP(AP_SSID, AP_PASS);
    Serial.printf("WiFi: AP mode  ssid=%s pass=%s  http://%s/\n", AP_SSID, AP_PASS,
                  WiFi.softAPIP().toString().c_str());
    netInfo = String("AP ") + AP_SSID + " " + WiFi.softAPIP().toString();
  } else {
    Serial.printf("WiFi: connected  http://%s/  (http://%s.local/)\n", WiFi.localIP().toString().c_str(), HOSTNAME);
    netInfo = WiFi.localIP().toString();
  }
  if (MDNS.begin(HOSTNAME)) {
    MDNS.addService("http", "tcp", 80);
  }
}

void setup() {
  Serial.begin(115200);
  pinMode(PIN_STATUS_LED, OUTPUT);
  digitalWrite(PIN_STATUS_LED, HIGH);  // off (active low)
  pinMode(PIN_TRIGGER_BTN, INPUT_PULLUP);
  delay(300);
  Serial.printf("\n[turret] XIAO ESP32S3 Sense tracking turret  (reset reason %d)\n", (int)esp_reset_reason());
  Serial.printf("[turret] psram %u bytes, detector: %s\n", (unsigned)ESP.getPsramSize(),
                HAVE_ESPDET ? "ESPDet-Pico person (esp-dl 3.x)" : (HAVE_ESP_DL ? "esp-dl 1.x face" : "none"));

  displayBegin();
  buzzerBegin();
  displayBoot("booting", "camera + wifi");
  tracker.begin();           // servos to center, settings from NVS
  {
    int m = tracker.settings.bootMode;
    if (m < 0 || m > 3) m = MODE_FACE;
#if !HAVE_ESP_DL && !HAVE_ESPDET
    if (m == MODE_FACE) m = MODE_MANUAL;    // no detector in this build
#endif
    tracker.setMode((Mode)m);
  }
  if (!cameraInit()) {
    // Keep going: manual/scan still work without a camera, web UI shows no stream.
    Serial.println("[turret] camera unavailable");
  }
  detector.begin();
  if (HAVE_ESPDET) Serial.printf("[turret] ESPDet-Pico person detector %s\n", personDetectBegin() ? "loaded" : "FAILED");
  frames.begin();
  wifiBegin();
  webBegin(&tracker, &frames, &stats);

  displayBoot("ready", netInfo.c_str());
  buzzerBeep(1000, 60);
  xTaskCreatePinnedToCore(controlTask, "control", 4096, nullptr, 3, nullptr, 1);
  xTaskCreatePinnedToCore(detectorTask, "detect", 16384, nullptr, 1, nullptr, 1);
  Serial.println("[turret] ready");
}

void loop() {
  static uint32_t lastBtn = 0;
  static bool btnWas = false;
  uint32_t now = millis();

  // Trigger button toggles the laser (debounced).
  bool btn = digitalRead(PIN_TRIGGER_BTN) == LOW;
  if (btn && !btnWas && now - lastBtn > 250) {
    tracker.setLaser(!tracker.laserOn());
    lastBtn = now;
  }
  btnWas = btn;

  // Status LED (active low): AP mode slow blink, locked solid, tracking short blink, else off.
  bool on;
  if (tracker.locked()) on = true;
  else if (apMode) on = (now % 2000) < 100;
  else if (tracker.targetFresh(now)) on = (now % 500) < 60;
  else on = false;
  digitalWrite(PIN_STATUS_LED, on ? LOW : HIGH);

  buzzerUpdate(tracker);
  static uint32_t lastDisp = 0;
  if (now - lastDisp > 250) {
    lastDisp = now;
    displayUpdate(tracker, stats, netInfo);
  }

  static uint32_t lastLog = 0;
  if (now - lastLog > 5000) {
    lastLog = now;
    Target t = tracker.lastTarget();
    Serial.printf("[turret] up=%us mode=%d pan=%.1f tilt=%.1f target=%s(%d,%d) fps=%.1f infer=%ums heap=%u\n",
                  (unsigned)(now / 1000), (int)tracker.mode(), tracker.pan(), tracker.tilt(), t.found ? "yes" : "no",
                  t.x, t.y, stats.fps, (unsigned)stats.inferMs, (unsigned)ESP.getFreeHeap());
  }
  delay(20);
}

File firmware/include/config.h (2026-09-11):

#pragma once

// ---------------------------------------------------------------------------
// WiFi: copy include/secrets.h.example to include/secrets.h and edit.
// With no secrets.h (or empty SSID) the turret starts its own AP.
// ---------------------------------------------------------------------------
#if defined(__has_include)
#if __has_include("secrets.h")
#include "secrets.h"
#endif
#endif

#ifndef WIFI_SSID
#define WIFI_SSID ""
#endif
#ifndef WIFI_PASS
#define WIFI_PASS ""
#endif

#define HOSTNAME        "turret"     // http://turret.local
#define AP_SSID         "turret"
#define AP_PASS         "turret123"  // min 8 chars
#define WIFI_CONNECT_MS 15000

// ---------------------------------------------------------------------------
// Pins (XIAO ESP32S3 silkscreen -> GPIO). D0..D3 are free on the Sense board;
// GPIO10..18,38..40,47,48 are the camera, GPIO21 is the user LED / SD CS,
// GPIO41/42 are the PDM mic.
// ---------------------------------------------------------------------------
#ifndef EXPANSION_BOARD
#define EXPANSION_BOARD  0
#endif

#if EXPANSION_BOARD
// XIAO on the Seeed Expansion Board: D1 is its user button (to GND), D3/A3 drives its
// buzzer transistor, D4/D5 are the OLED I2C. Keep the servo/laser lines off those.
#define PIN_SERVO_PAN    1   // D0
#define PIN_SERVO_TILT   3   // D2
#define PIN_LASER       43   // D6 (Grove UART TX pin, free)
#define PIN_TRIGGER_BTN  2   // D1  expansion-board user button
#define PIN_BUZZER       4   // D3  expansion-board buzzer
#else
#define PIN_SERVO_PAN    1   // D0
#define PIN_SERVO_TILT   2   // D1
#define PIN_LASER        3   // D2  (laser / LED "fire" output, active HIGH)
#define PIN_TRIGGER_BTN  4   // D3  (momentary to GND, optional)
#endif
#define PIN_STATUS_LED  21   // onboard user LED, active LOW

// LEDC channels 0/1 (timer 0) are used by the camera XCLK.
#define LEDC_CH_PAN      2
#define LEDC_CH_TILT     3
#define SERVO_FREQ_HZ    50
#define SERVO_RES_BITS   14  // 50 Hz / 14 bit = 1.22 us per step; S3 hardware maximum
// MG90S: 180 deg over roughly 544..2400 us on most units. Wider ranges drive the
// gear train into the end stops and cook the motor; widen only after checking travel.
#define SERVO_MIN_US     544
#define SERVO_MAX_US     2400

// Mechanical limits (degrees). Tilt limits keep the head off the yoke base.
#define PAN_MIN_DEG      0.0f
#define PAN_MAX_DEG    180.0f
#define TILT_MIN_DEG    35.0f
#define TILT_MAX_DEG   145.0f
#define PAN_CENTER_DEG  90.0f
#define TILT_CENTER_DEG 90.0f

// Camera
#define CAM_W            240
#define CAM_H            240
#define CAM_FRAMESIZE    FRAMESIZE_240X240
#define CAM_XCLK_HZ      20000000

// Control loop
#define CONTROL_HZ       50

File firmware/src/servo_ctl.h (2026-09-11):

#pragma once
#include <Arduino.h>
#include "config.h"

// Hobby servo on an LEDC channel, 50 Hz, 16-bit duty.
// Works on arduino-esp32 2.x (ledcSetup/ledcAttachPin) and 3.x (ledcAttachChannel).
class ServoOut {
 public:
  void attach(int pin, int channel, float minDeg, float maxDeg) {
    _pin = pin;
    _ch = channel;
    _min = minDeg;
    _max = maxDeg;
    // ESP32-S3 LEDC is limited to 14-bit resolution (16 fails with "No more LEDC channels").
#if ESP_ARDUINO_VERSION_MAJOR >= 3
    ledcAttachChannel(_pin, SERVO_FREQ_HZ, SERVO_RES_BITS, _ch);
#else
    ledcSetup(_ch, SERVO_FREQ_HZ, SERVO_RES_BITS);
    ledcAttachPin(_pin, _ch);
#endif
  }

  void writeDeg(float deg) {
    if (deg < _min) deg = _min;
    if (deg > _max) deg = _max;
    _deg = deg;
    uint32_t us = SERVO_MIN_US + (uint32_t)((SERVO_MAX_US - SERVO_MIN_US) * (deg / 180.0f));
    writeUs(us);
  }

  void writeUs(uint32_t us) {
    const uint32_t period_us = 1000000UL / SERVO_FREQ_HZ;
    const uint32_t maxDuty = (1UL << SERVO_RES_BITS) - 1;
    uint32_t duty = (uint32_t)(((uint64_t)us * maxDuty) / period_us);
#if ESP_ARDUINO_VERSION_MAJOR >= 3
    ledcWrite(_pin, duty);
#else
    ledcWrite(_ch, duty);
#endif
  }

  void detach() {
#if ESP_ARDUINO_VERSION_MAJOR >= 3
    ledcDetach(_pin);
#else
    ledcDetachPin(_pin);
#endif
  }

  float deg() const { return _deg; }
  float minDeg() const { return _min; }
  float maxDeg() const { return _max; }

 private:
  int _pin = -1, _ch = -1;
  float _min = 0, _max = 180, _deg = 90;
};

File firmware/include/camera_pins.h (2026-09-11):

#pragma once
// Seeed Studio XIAO ESP32S3 Sense, OV2640 on the expansion board.
// Matches CAMERA_MODEL_XIAO_ESP32S3 in the arduino-esp32 CameraWebServer example.
#define PWDN_GPIO_NUM   -1
#define RESET_GPIO_NUM  -1
#define XCLK_GPIO_NUM   10
#define SIOD_GPIO_NUM   40
#define SIOC_GPIO_NUM   39

#define Y9_GPIO_NUM     48
#define Y8_GPIO_NUM     11
#define Y7_GPIO_NUM     12
#define Y6_GPIO_NUM     14
#define Y5_GPIO_NUM     16
#define Y4_GPIO_NUM     18
#define Y3_GPIO_NUM     17
#define Y2_GPIO_NUM     15
#define VSYNC_GPIO_NUM  38
#define HREF_GPIO_NUM   47
#define PCLK_GPIO_NUM   13

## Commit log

2026-09-11 still-there: XIAO ESP32S3 Sense face/torso tracking turret
    Firmware (PlatformIO, arduino-esp32 2.0.17): esp-dl face acquisition, CAMShift torso
    tracking, 50 Hz pan/tilt control with lock hysteresis, web UI + MJPEG, expansion-board
    OLED/buzzer variant. OpenSCAD enclosure (base, yoke, head) for MG90S servos with STLs
    and a Flash Studio project for the Creator 5 Pro. BOM with links, bring-up notes,
    and the full design session transcript.
    [base.stl, base_lid.stl, head.stl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]
2026-09-11 espdet-pico: whole-body person detection with esp-dl 3.3.11 ESPDet-Pico
    New env xiao_espdet: plain Arduino on the pioarduino stable platform (Arduino 3.3.6),
    esp-dl 3.3.11 ESP32-S3 subset and espressif/pedestrian_detect 0.3.2 vendored as PlatformIO
    libraries, model embedded 16-byte aligned via .incbin, prebuilt fbs_model linked by an extra
    script. Person mode acquires on the body box (masked / turned-away people work) and seeds the
    torso color tracker from its upper part; aim point is a fraction down the body. New settings
    aim down body / person score threshold; overlay falls back to raw RGB565 drawing when fb_gfx
    is absent. Verified on hardware: ~200 ms per detection, 6-7 fps, no resets.
    m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
    [display.cpp, main.cpp, tracker.cpp]
2026-09-11 espdet-pico: enable the expansion-board OLED and buzzer in xiao_espdet
    U8g2 builds cleanly on the Arduino 3.3.6 core; OLED detected at 0x3C on hardware.
2026-09-11 espdet-pico: draw the body-detector seed box and label in magenta
    Distinguishes the ESPDet whole-body box from the esp-dl face box (green on main).
2026-09-11 BOM: laser module options (5 mW, Class 2 alternatives) and driver transistor
2026-09-12 CAD: measured MG90S horn geometry; single-arm head pocket, double-arm disc pocket
    Measured on the SupSeek kit: hub 6.8 dia, arm 5.1 x 2.0, single arm 18 (boss->arm 3.8, hub top
    6.4), double arm 31.2 (boss->arm 5.85, hub top 6.26), ear holes 27.8/28.0, ear top->boss 7.3/7.5.
    Round cross-horn pockets replaced by arm channels with hub counterbores and continuous screw
    slots. Horn-side head wall 6.5, disc 5.0, pilot slots 27.3..28.5. STLs, previews, 3MF and
    README regenerated; sliced 3h14m / 75 g PETG, no warnings.
    [base.stl, base_lid.stl, head.stl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]
2026-09-12 CAD notes: ear span is 32.2 (the 31.2 reading was the double-arm horn)
    [turret.scad]
2026-09-12 OLED recovery, Person as power-up mode, lib_ignore for the 2.0.x envs
    - display: I2C bus recovery, 1.5 s probe retry at boot, re-probe every 2 s when missing,
    re-init every 15 s so a panel reset by a supply dip comes back without a reboot
    - boot mode from NVS (default Person); Save settings stores the current mode
    - 2.0.17 envs ignore the vendored esp-dl 3.x libraries (LDF picked them up by header)
    - README: envs described side by side ahead of merging into main
    [display.cpp, main.cpp, tracker.cpp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]
2026-09-12 BOM: horn screw lengths after the measured-horn wall changes (M2x8 head, M2x6 disc); servo screws are supplied
2026-09-13 CAD: WiFi patch antenna accommodation
    The XIAO ESP32S3 has no on-board antenna. Head lid gets a 22 x 42 mm plate on its outer face
    for the kit 20 x 40 adhesive FPC patch with a 4 x 8 coax slot at the patch center; a 1.6 mm coax
    groove runs down the pivot-side wall from behind the expansion PCB to the back opening
    (coax_side mirrors it). Lid prints plate-down. STLs, previews, 3MF (3h18m / 77 g) and README
    regenerated.
    [base.stl, base_lid.stl, head.stl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]
2026-09-13 xiao_espdet: build for the XIAO ESP32S3 Plus (16 MB flash, default_16MB partitions)
    Project board file boards/seeed_xiao_esp32s3_plus.json (XIAO_ESP32S3_Plus variant from the 3.3.x
    core). App slot grows from 3.3 MB to 6.5 MB; the ESPDet build now uses 46 %.
2026-09-13 Boot-mode default fix, OLED re-probe limited to 30 s after boot
    First-boot default write no longer stores the not-yet-set mode (it forced Manual on a fresh
    board). OLED: a panel absent at boot is re-probed only during the first 30 s; a present panel
    keeps the 15 s re-init.
    [display.cpp, tracker.cpp, tracker.h]
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2026-09-13 CAD: head cradle for the measured XIAO ESP32S3 Plus + camera stack
    Camera module held in an 8.6 mm square socket behind a 7.4 mm window (the flex pushes it in);
    XIAO located by two pads at its exposed USB-end corners plus lid posts with 0.2 mm clearance;
    foam-gapped standoffs at the camera board far-end corners. Interior 18.8 x 26.25 x 20 for the
    17.76 x 21.25 XIAO under the 18 mm wide camera board, lens on center. Coax groove moved to the
    far end where the U.FL is. STLs, previews, 3MF (3h23m / 78 g) and README regenerated.
    [base.stl, base_lid.stl, head.stl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]
2026-09-13 CAD: coax groove on the pivot side (U.FL confirmed opposite the horn channel); axis note fixed
    [base.stl, base_lid.stl, head.stl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]
2026-09-13 CAD: measured lens base 2.0 mm, base back to lens front 5.37 mm; board stack depths re-derived
    [base.stl, base_lid.stl, head.stl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]
2026-09-13 CAD: open the lower collar wall behind the lens base for the flex exit
    [base.stl, base_lid.stl, head.stl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]
2026-09-13 make_project: --parts= for partial-reprint projects; head+lid project
    [turret_creator5pro_head_head_lid.3mf]
2026-09-13 CAD: laser lead drop through the head top, antenna plate below the head, lid grommet removed
    [base.stl, base_lid.stl, head.stl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]
2026-09-14 Wiring path: harness hole outside the disc, arm A tie slots, pan servo flange-below as built; README wiring section, BOM row 7
    [base.stl, base_lid.stl, head.stl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]
2026-09-14 CAD: assembly mock draws the single-arm tilt horn pointing down
    [base.stl, base_lid.stl, head.stl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]
2026-09-14 CAD: USB-end lid posts moved inboard, off the soldered XIAO pads
    [base.stl, base_lid.stl, head.stl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]
2026-09-14 Design review fixes: lid bosses inside the lip, XIAO front stops off the buttons, antenna plate above the head (USB notch open), M3x8 pivot, arm-edge tie slots, blind disc slots removed, vents off th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
    [base.stl, base_lid.stl, head.stl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]
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2026-09-14 CAD: base lid vent slots cut through (were 0.5 mm blind)
    [base.stl, base_lid.stl, head.stl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]
2026-09-14 CAD: note camera board far corners verified bare
    [turret.scad]
2026-09-14 CAD: note XIAO back verified bare at the lid posts
    [turret.scad]
2026-09-14 CAD: USB-end front stop on the USB-C shell so the board stack cannot pivot
    [base.stl, base_lid.stl, head.stl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]
2026-09-14 CAD: head lid outer face flat across the whole lid plus the antenna fin; no overhang on the bed
    [base.stl, base_lid.stl, head.stl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]
2026-09-14 CAD: coax enters through a notch at the lid's top edge (patch coax is on the exposed face); center slot removed; README antenna step
    [base.stl, base_lid.stl, head.stl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]
2026-09-14 CAD: camera-board front stops moved to its USB-end corners over the b2b connector; far end is the 2 mm flex socket; b2b gap 3.11 measured; collar open top and bottom
    [base.stl, base_lid.stl, head.stl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]
2026-09-14 CAD: front stops bear on the flex socket top at the camera board's far end (over the b2b connector); free end near the USB-C untouched
    [base.stl, base_lid.stl, head.stl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]
2026-09-14 CAD: lens collar 2.5 deep to clear the mic can on the camera board
    [base.stl, base_lid.stl, head.stl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]
2026-09-14 CAD: lens collar open only on the far-end side where the flex exits
    [base.stl, base_lid.stl, head.stl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]
2026-09-14 CAD: coax groove runs from below the XIAO far edge up into the ceiling corner so the U.FL cable can exit over the edge or sideways
    [base.stl, base_lid.stl, head.stl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]
2026-09-14 CAD: coax groove 3 mm deep for the bend radius
    [base.stl, base_lid.stl, head.stl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]
2026-09-14 CAD: laser saddle front sloped 45 deg to the head front edge; prints without a ceiling overhang
    [base.stl, base_lid.stl, head.stl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]
2026-09-14 CAD: head horn channel back to plain vertical walls (full horn coupling); roof option left off
    [base.stl, base_lid.stl, head.stl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]
2026-09-14 CAD: lid coax notch moved to the pivot-side top corner over the groove end; groove now exits the head
    [base.stl, base_lid.stl, head.stl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]
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2026-09-17 CAD: inlet board mounts flat on an internal pad with two M2 pilots 16 mm apart; receptacle slot 10 x 4.2 open to the rim; README/BOM updated
    [base.stl, base_lid.stl, head.stl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]
2026-09-17 CAD: record the MG90S lead exit and why the flange-on-plate pan mount never worked
    [turret.scad]
2026-09-17 CAD: inlet moved to the +X (back) wall, 27 mm behind the pan servo body; vents to the front
    [base.stl, base_lid.stl, head.stl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]
2026-09-17 README: splice points are perfboard scraps with one wire per hole, not doubled header tails
2026-09-18 README: assembly order, head onto the yoke before the tilt servo goes into arm A
2026-09-18 CAD: tilt horn seats 2 mm high on the spline as assembled; arm B moved 2 mm outward, arm A stays at the disc edge
    [base.stl, base_lid.stl, head.stl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]
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2026-09-19 firmware: invert pan/tilt act at the servo output so manual, scan, click-to-aim and tracking reverse together
    [tracker.cpp, tracker.h]
2026-09-19 CAD: laser bore 7.3 for the Quarton VLM-650-03 as bought; saddle height and width follow the bore; BOM/README
    [base.stl, base_lid.stl, head.stl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]
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2026-09-21 CAD: USB-C inlet mounted outside on a flat facet in the back wall, pilots from outside, 13 mm slot; inside mount abandoned (plug could not reach)
    [base.stl, base_lid.stl, head.stl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]
2026-09-21 CAD: harness hole becomes a 6 x 12 arc slot following the rim so a servo plug passes through
    [base.stl, base_lid.stl, head.stl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]
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2026-09-22 firmware: two-detection confirmation for new tracks, top-quarter reject at the tilt ceiling, 1.5 s unconfirmed leash (migrated), stuck-window drop
    [main.cpp, tracker.cpp, tracker.h]
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

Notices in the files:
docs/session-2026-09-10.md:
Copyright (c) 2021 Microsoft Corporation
